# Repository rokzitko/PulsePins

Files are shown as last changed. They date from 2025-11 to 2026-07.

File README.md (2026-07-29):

# PulsePins Pulse Sequencer




PulsePins is an open-hardware FPGA pulse sequencer for laboratory timing and digital control. The released DE10-Nano design provides 32 digital outputs and a 10 ns programmable time step at a 100 MHz streamer clock. Use it for triggers, gates, digital buses, and DAC or DDS control; it does not generate analog or RF waveforms directly.

## Start here

Choose the path that matches what you want to do first:

| Goal | Start here |
| ---- | --- |
| Bring up a DE10-Nano | [Quick start](docs/docs/quick_start.md) |
| Choose a command or API | [Tool chooser](docs/docs/choose_tool.md) |
| Follow a complete lab workflow | [Worked examples](docs/docs/examples.md) |
| Understand the sequencer | [Sequencer model](docs/docs/sequencer_model.md) |
| Modify or extend PulsePins | [Hacking guide](HACKING.md) and [extension cookbook](docs/docs/extension_cookbook.md) |

## At a glance

| Item | Released DE10-Nano design |
| ---- | --- |
| Digital output | 32-bit bus, 3.3 V LVTTL |
| Timing | 10 ns programmable time step at a 100 MHz streamer clock |
| Sequence delivery | HPS-driven FIFO or memory-backed DMA transfers up to 512 MB |
| Control | Command-line tools, C++, Python, SCPI-style TCP, and a browser interface |
| Checks | FPGA readback encoder, CRC and FIFO diagnostics, and board self-tests |
| Design files | SystemVerilog/Verilog RTL, software, and KiCad sources under the MIT License |

## Documentation

[User and reference manual](http://auger.ijs.si/pulsepins/site/) ([source](docs/docs/index.md))

Useful contributor documents:

* [Hacking guide](HACKING.md)
* [Contribution guide](CONTRIBUTING.md)
* [Build and deployment](docs/docs/build.md)
* [Development guide](docs/docs/hacking.md)

## Recipes

Reusable command examples for the PulsePins command-line tools are stored in [`recipes/`](recipes/).
These files are separate from `tests/` so test executables and example command invocations are easier to find.

## License

This project is released under the MIT License. You may use, copy, modify, merge, publish, distribute, sublicense,
and/or sell the software and FPGA firmware (including RTL sources and generated bitstreams), including in commercial
and closed-source products. The only conditions are that you preserve the original copyright and license notice in all
substantial portions of the software/firmware, and that the software and firmware are provided “as is”, without any
warranty or liability on the part of the authors.

If you use PulsePins in scientific work, please cite:

> R. Žitko, *PulsePins: Open-hardware digital pulse sequencer for time-resolved experiments*, Zenodo (2025), [doi:10.5281/zenodo.17903233](https://doi.org/10.5281/zenodo.17903233).

### BibTeX

```bibtex
@misc{pulsepins_1_0,
  author       = {Žitko, Rok},
  title        = {PulsePins: Open-hardware digital pulse sequencer for time-resolved experiments},
  year         = {2025},
  publisher    = {Zenodo},
  version      = {1.0},
  doi          = {10.5281/zenodo.17903233},
  url          = {https://doi.org/10.5281/zenodo.17903233}
}
```

## Acknowledgments

This project incorporates code from the project [rsyocto](https://github.com/robseb/rsyocto) (c) Robin Sebastian, licensed under the MIT License.
See `third_party/rsyocto/LICENSE` for details.

[Rok Zitko](http://auger.ijs.si/nano), [rok.zitko@ijs.si](mailto:rok.zitko+pulsepins@ijs.si), 2025

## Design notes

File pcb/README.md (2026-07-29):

KiCad design files for printed-circuit boards ("ppshields"). These are reference designs for a quick start and
testing. The idea is that users modify these designs for their particular needs.

* ppshield_pmod: ppshield with Pmod interfaces

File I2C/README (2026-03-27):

i2cdetect -l

sudo i2cdetect -y 1

sudo i2cdetect -y -r 1

sudo i2cdetect -y -r -a 1

Note: the scripts require `smbus2`: `pip3 install smbus2`

Fix the version number in `gpg-1.13.1_unknown-py3.8.egg-info`:
`/usr/lib/python3.8/site-packages/gpg-1.13.1_unknown-py3.8.egg-info`

Remove `-unknown`.

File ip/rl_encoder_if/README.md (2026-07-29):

PulsePins readback / run-length encoder subsystem.

This directory contains the RTL used to observe `qout` activity, compress it back into run-length-encoded elements, and expose that captured stream to software for verification and debugging.

## Main files

- `rl_encoder_if.sv` - Avalon-ST/Avalon-MM wrapper around the readback encoder core
- `rl_encoder.sv` - core run-length encoder plus dual-clock FIFO buffering
- `rl_config.vh` - shared widths and configuration constants

## Architecture overview

The readback path is the mirror image of the streamer datapath:

1. sampled output symbols arrive on `qin`
2. normal builds sample valid input words on `qin_clk`; the alternate strobe-clocked mode is dormant behind `WEIRD_CLOCK`
3. `rl_encoder.sv` groups consecutive equal values into `{count, value}` runs
4. a dual-clock FIFO decouples the sampled input domain from HPS-side reads
5. `rl_encoder_if.sv` exports the captured runs as Avalon-ST data and adds status/control registers

This subsystem is mainly used for:

- self-test of streamer output correctness
- CRC-based integrity checking
- debugging external signals when the physical output enable `oe` is deasserted

## Programming model

`rl_encoder_if.sv` exposes:

- Avalon-ST output carrying encoded `{control=0, counter, data}` elements
- Avalon-MM control/status registers for reset, active-mode status, pulse count, FIFO-empty state, overflow, and CRC32

The wrapper also maintains a pulse counter and CRC in the sampled-input domain so software can compare the observed stream against the transmitted reference.

## Reading order for maintainers

1. `rl_encoder_if.sv`
2. `rl_encoder.sv`
3. `rl_config.vh`
4. `c++/readback.hh`
5. `docs/docs/readback.md`

## Verification and related docs

- subsystem overview: `docs/docs/readback.md`
- related streamer docs: `docs/docs/streamer.md`
- HPS-side wrapper: `c++/readback.hh`

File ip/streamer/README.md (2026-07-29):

PulsePins streamer subsystem.

This directory contains the RTL for the main pulse-sequence engine: it accepts encoded sequence elements on the control side, expands them into output updates, applies configured trigger and gating behavior, and emits the final `qout` stream in the selected streaming clock domain.

## Main files

- `st_interface.sv` - Avalon-ST data ingress plus Avalon-MM control/status wrapper around the streamer core
- `streamer.sv` - top-level datapath glue joining FIFOs, decoder, trigger chain, and output flow control
- `config.vh` - shared widths, control-bit definitions, register enums, and FIFO sizing parameters
- `input_fifo.sv` - control-side FIFO that buffers incoming sequence elements
- `preprocessor.sv` - optional second-level replay/store stage for short subsequences
- `rl_decoder.sv` - run-length decoder that expands encoded elements into output updates
- `output_fifo.sv` - dual-clock FIFO bridging control-side decode logic into the `streamer_clk` output domain
- `and_trigger.sv` - simple single-stage mask/pattern trigger block
- `chain_trigger.sv` - multi-stage trigger program loader and runtime trigger state machine
- `prng.sv` - pseudorandom data source used by PRNG elements

## Architecture overview

The streaming path is intentionally split into two domains:

1. control-side logic in `clk`
2. output-side logic in `streamer_clk`

At a high level the flow is:

1. HPS-side software or the DMA engine sends encoded `{control, counter, data}` elements into `st_interface.sv`
2. `st_interface.sv` byte-swaps them into the internal layout and forwards them to `streamer.sv`
3. `input_fifo.sv` absorbs bursty HPS-side traffic and provides backpressure through `asi_ready`
4. regular elements go to `rl_decoder.sv`, while trigger elements are consumed by `chain_trigger.sv`
5. decoder output is buffered by `output_fifo.sv`, which crosses into `streamer_clk`
6. `chain_trigger.sv` decides when output is allowed to advance
7. gating and stop logic further qualify output reads from the output FIFO
8. `qout`, `qout_valid`, and `qout_strobe` become the external streamer outputs

## Programming model

The external software-visible wrapper is `st_interface.sv`.

It exposes:

- an Avalon-ST ingress port carrying encoded sequence elements
- an Avalon-MM control/status port for trigger control, output override, gating, CRC readout, and FIFO statistics
- direct trigger and gate inputs used at runtime in the `streamer_clk` domain

The Avalon-ST ingress accepts a channel tag for integration with channel-aware width adapters. `st_interface.sv` ignores the tag after the adapter has used it to keep upstream partial elements separate.

Important behavioral points:

- regular sequence elements describe output updates and durations
- trigger elements are intercepted before decode and loaded into the trigger chain
- `initial_value` defines the observable output before the trigger fires
- `qout_select` can override the normal streamer output for debugging or manual output driving
- `gate_enable` controls whether the output-side FIFO is allowed to advance once triggering has started
- `done` reflects successful completion of the buffered output stream
- `buffer_error` indicates output-side underrun
- static output/gating configuration written from Avalon-MM crosses into `streamer_clk` as a
  coherent CDC bundle and is applied only while the streamer is idle or in streamer reset
- live status, CRC, output value, and output-side counter readout values are control-domain snapshots
  of `streamer_clk` state, not direct asynchronous samples

## Key customization points

If you want to customize the streamer, the usual starting points are:

- register map or external control behavior - `st_interface.sv`
- encoded element semantics - `config.vh`, `rl_decoder.sv`, `preprocessor.sv`
- trigger behavior - `chain_trigger.sv`, `and_trigger.sv`
- output pacing, strobe timing, underrun behavior - `output_fifo.sv`
- buffering and throughput tradeoffs - `config.vh`, `input_fifo.sv`, `output_fifo.sv`

## Reading order for maintainers

1. `config.vh`
2. `st_interface.sv`
3. `streamer.sv`
4. `rl_decoder.sv`
5. `preprocessor.sv`
6. `output_fifo.sv`
7. `chain_trigger.sv`

That order follows the boundary from software-visible control interfaces toward the deeper implementation details.

## Verification and related docs

- run RTL tests: `make -C ip test`
- subsystem overview: `docs/docs/streamer.md`
- low-level hardware details: `docs/docs/details.md`
- CDC and clock ownership: `docs/docs/clock_domain.md`
- readback verification path: `docs/docs/readback.md`

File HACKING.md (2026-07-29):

# Hacking on PulsePins

PulsePins is meant to be hacked on, adapted, and extended.

Contributions are welcome across RTL, C++, Python, documentation, tests, board support, examples, measurement workflows, and experimental integration ideas. You do not need to start with a large feature; small fixes, examples, and documentation improvements matter too.

## Good first contribution areas

- Documentation: clean up wording, expand guides, add examples, improve onboarding
- C++ tools: improve `pptool`, add options, improve formatting, add tests for parsing and sequence handling
- Python bindings: improve packaging, examples, and tests in `python/`
- RTL and simulation: add or improve testbenches under `ip/`
- Recipes and examples: add practical command sequences in `recipes/`
- Worked examples: capture real lab workflows, timing setups, and instrument integrations

## Contribution paths

### No hardware required

You can contribute without a board if you work on:

- documentation under `docs/` and top-level `README*` files
- sequence parsing and representation in `c++/`
- Python bindings in `python/` (build/import testing on a development machine is useful, but production Python builds still happen on the DE10-Nano)
- RTL testbenches and simulation-only RTL work under `ip/`
- recipes, examples, and test infrastructure

Good first commands:

```bash
make dev-check
make -C ip test
```

`dev-check` is the default local contributor check.
`make -C ip test` runs RTL simulation testbenches if the required simulator tools are installed.

For Python specifically:

- running `make -C python USE_PREGENERATED=1 build test-host` on a development machine checks the host-buildable bindings and non-hardware tests
- the supported production build of the Python modules still happens on the DE10-Nano
- true Python cross-compilation is not currently supported

### Hardware helps, but is not always required

These areas benefit from access to a board but can still be developed partially without one:

- CLI tool UX and error messages
- sequence-generation logic
- counter/timestamp/frequency-meter docs and helper code
- deployment scripts and image staging

### Hardware required

You will usually need a DE10-Nano and the PulsePins bitstream/runtime environment for:

- end-to-end streamer behavior
- timing-sensitive measurements
- clocking, PPS, and external trigger validation
- board bring-up and interface-shield testing
- hardware-backed regression verification

The default documented hardware baseline is intentionally minimal:

- `DE10-Nano` only
- latest released pre-built PulsePins image
- no extra wiring for the baseline verification flow

For that baseline, the board:

- obtains its network address via DHCP
- can be reached over SSH as user `root` with password `eit`
- can also be accessed over the UART USB serial interface if needed

## Build/test map

| Area | Main location | Hardware needed | Main command |
| ---- | --- | --- | --- |
| Local checks | repo root | no | `make dev-check` |
| Docs | `docs/` | no | `make -C docs site` |
| C++ tools | `c++/` | not always | `make -C c++ build` |
| Python bindings | `python/` | not always | `make -C python USE_PREGENERATED=1 build test-host` |
| RTL simulation | `ip/` | no | `make -C ip test` |
| Fast board smoke | repo root | yes | `make board-smoke` |
| Full FPGA build | repo root | toolchain required | `make` |
| Board deployment | repo root, `image/` | yes | `make copy_all` |

## Baseline hardware workflow

The baseline bring-up and verification flow is:

1. boot the latest released pre-built image on a DE10-Nano
2. connect over SSH
3. run `run_all_tests`

Expected result:

- the command exits successfully
- it prints a clear pass message
- it currently takes a few minutes, roughly around 7 minutes at the default 100 MHz streaming frequency

That runtime should be treated as approximate; it may change as the test suite grows.

## Updating a board from the current repository state

The current recommended contributor update flow is:

1. build the latest GitHub version
2. run `make copy_all`
3. SSH to the DE10-Nano
4. from the root home directory on the board, run:

```bash
FPGA-writeConfig -f pulsepins.rbf
```

5. run `run_all_tests` again

For now, treat this FPGA reload step as required after `make copy_all`.

## Optional hardware profile: PP_PMOD

`PP_PMOD` is an optional reference shield. It is not part of the required baseline, and it is not a prebuilt product.

Its KiCad design is published so people can build it, modify it, or use it as a starting point for custom boards.

Useful capabilities include:

- Pmod connectors for expansion modules
- one SMA trigger input with comparator threshold control
- two buffered SMA outputs
- external clock and PPS inputs
- Qwiic I2C connector
- optional on-board `AD5693` DAC
- optional on-board `MCP9808` temperature sensor
- status LEDs

Verified/useful optional workflows around `PP_PMOD` include:

- LED Pmod modules for visible output patterns
- onboard `MCP9808` temperature reads
- external `TMP117` over Qwiic/I2C
- `Pmod DA3` for fixed-voltage DAC output
- external clock verification with `ppfreq`
- PPS verification with `ppts`
- buffered-output use with oscilloscopes, logic analyzers, spectrum analyzers, and counters

Known-good external clock examples include:

- lab signal generators
- OCXO/GPSDO references
- CMOS oscillator modules

PPS has been checked with a GNSS receiver PPS output.

## Suggested first contributions

- improve a doc page that feels too author-centric
- add a missing example or recipe
- improve a command-line help message
- add a small simulation test case for an IP block
- fix naming consistency or formatting in tool output
- document a real hardware workflow once you have verified it

Worked examples are especially valuable. Example-driven documentation is one of the best ways to make PulsePins approachable.

### Community-contribution areas that would help a lot

- worked examples from real physics/lab scenarios
- Pmod module and sensor writeups
- custom shield or daughterboard notes
- wiring diagrams and timing diagrams
- screenshots, scope traces, and logic-analyzer captures
- photos of custom hardware setups

Typical application areas where community examples would be especially appreciated include:

- pulse sequencing for lasers, shutters, and detectors
- synchronized triggering of cameras and instruments
- delay generation for time-resolved measurements
- DDS/DAC control for frequency or amplitude sweeps

Lua scripting is also a promising extension area, but it is still early-stage and only lightly documented.

## Reliability matters

High reliability is a major project goal.

Simulation-only RTL work is therefore very valuable and strongly encouraged, especially when it improves:

- testbenches
- interface validation
- CDC and reset correctness
- executable documentation of behavior

Testbenches are useful not only for verification, but also for documenting interfaces and intended functionality.

## Community interaction

For now, use GitHub Issues for:

- bug reports
- ideas and feature requests
- questions
- example writeups
- hardware setup notes

## Working style

- Prefer small, focused changes
- Keep documentation close to the code it explains
- If behavior changes, update docs and tests in the same change when practical
- If hardware behavior is uncertain, document the uncertainty instead of guessing

## Where to look next

- `CONTRIBUTING.md`
- `docs/docs/build.md`
- `docs/docs/development.md`
- `docs/docs/testing.md`
- `docs/docs/getting_started_no_hardware.md`
- `docs/docs/getting_started_hardware.md`

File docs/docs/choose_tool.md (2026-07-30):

# Choose the right tool

PulsePins exposes the same hardware through task-specific commands, C++ and Python APIs, a SCPI-style network service, and a browser interface. Start with the narrowest interface that already matches the job.

This page describes the current source-tree command set. Older released images may provide fewer commands; check the selected release notes when a tool is unavailable.

## Choose by task

| Goal | Start with | Why |
| ---- | --- | --- |
| Set up and validate a released board | [Quick start](quick_start.md) | linear image, access, self-test, and first-output procedure |
| Generate a periodic signal, PWM, or finite burst | [`ppfg`](ppfg.md) | direct frequency, period, duty-cycle, and burst controls |
| Emit a pulse after a trigger and delay | [`ppdelay`](ppdelay.md) | one-shot delay-generator workflow |
| Run the smallest live output smoke test | [`pphelloworld`](pphelloworld.md) | immediate repeating output without a sequence file |
| Play a saved sequence | [`ppplay`](ppplay.md) | canonical text plus derived binary and VCD input |
| Capture, inspect, or replay qualified output samples | [`ppread`](ppread.md) and [Readback](readback.md) | `qout_valid`-qualified runs as text, VCD, or a current-build binary snapshot |
| Run built-in hardware checks | [`pptest`](pptest.md) and [Testing procedures](testing.md) | streamer, trigger, preprocessor, and readback validation |
| Measure clocks | [`ppfreq`](ppfreq.md) | external, internal, streamer, and core clock measurements |
| Inspect PPS or timestamp events | [`ppts`](ppts.md) | timestamp stream and interval reporting |
| Exercise event counters | [`ppcounter`](ppcounter.md) | built-in deterministic or pseudorandom counter test sequences |
| Monitor AUX pin levels | [`ppaux`](ppaux.md) | formatted sampling of the read-only CLI path |
| Read the PP_PMOD temperature sensor | [`pptemp`](pptemp.md) | MCP9808 board-peripheral access |
| Debug trigger sources and masks | [`pptrig`](pptrig.md) | trigger-combiner configuration and live state |
| Inspect or override output routing | [`ppqout`](ppqout.md) | output-combiner modes, masks, and force values |
| Reset an interrupted or infinite stream | [`ppreset`](ppreset.md) | return the primary streamer to a known idle state |
| Calculate a PLL profile without hardware | [`pllcalc`](pllcalc.md) | standalone clock-profile calculation |
| Automate from a script or notebook | [Python API](python.md) | generated sequences and experiment integration |
| Add a command or direct hardware wrapper | [C++ API](cpp.md) | native access to the existing runtime and hardware classes |
| Control a board over the network | [`ppscpi`](ppscpi.md) | line-oriented remote instrument control |
| Operate interactively from a browser | [`ppwebgui`](ppwebgui.md) | live state plus trigger, routing, and sequence controls |

## Choose an interface layer

| Interface | Best fit | Main tradeoff |
| --- | --- | --- |
| Command-line tools | immediate shell use and existing single-purpose operations | limited composition beyond shell scripts |
| Python API | notebooks, sweeps, generated sequences, and larger measurement scripts | board-native bindings and workstation SCPI clients have different deployment models |
| C++ API | new tools, direct wrappers, and performance-sensitive board-side work | requires native build and lower-level project knowledge |
| SCPI server | remote orchestration and instrument-style clients | unauthenticated control; restrict the bind address or use a trusted network |
| Web interface | interactive setup, status, and manual operation | intended for trusted networks rather than unattended automation |

Use the command line first when a dedicated tool already provides the operation. Move to Python or C++ when sequence generation, repetition, error handling, or integration logic starts dominating the shell commands.

## Sequence file formats

| Format | Use it when |
| --- | --- |
| PulsePins text | the sequence should remain readable and editable |
| VCD | a flattened waveform should be inspected in a waveform-oriented tool and the documented projection limits are acceptable |
| PulsePins binary (`.ppbin`) | a normalized current-build sequence snapshot is useful and matching field widths are available |

PulsePins text is the canonical user-facing format. See [PulsePins text sequence format](sequence_format.md), [`ppplay`](ppplay.md), and [`ppread`](ppread.md) for fidelity and interface-specific behavior.

## Common paths

First board:

1. Follow [Quick start](quick_start.md).
2. Confirm `run_all_tests` reports `SUCCESS`.
3. Follow [First finite output](manual/first_output.md).
4. Select the next command or interface from the task table above.

Repeatable capture and replay:

1. Start [`ppread`](ppread.md) before the signal source and keep the capture running.
2. Generate with [`ppfg`](ppfg.md), [`ppdelay`](ppdelay.md), or a custom sequence while capture is active.
3. Inspect VCD or text output.
4. Replay with [`ppplay`](ppplay.md).

Readback records live qualified samples; it cannot recover a finite waveform that completed before `ppread` started, no-strobe states, or the elapsed time in invalid gaps. See [Capture and replay](manual/capture_replay.md) for the two-terminal workflow.

Peripheral transaction:

1. Validate the base output path with [`pptest`](pptest.md).
2. Check routing with [`ppqout`](ppqout.md) if needed.
3. Generate the transaction with the C++, Python, or helper-tool layer.
4. Play and verify the resulting sequence.

## Experimental reference

[`ppgpsdo`](ppgpsdo.md) remains an experimental GPSDO reference implementation rather than a recommended user-manual workflow. Establish and verify the complete oscillator-to-timestamp feedback path before treating it as a control loop for laboratory use.

For complete command-and-observation chapters, continue with the [User manual](examples.md).

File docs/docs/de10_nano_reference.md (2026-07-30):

# DE10-Nano signal reference

This page describes the board-facing signals in the released 32-bit DE10-Nano design. The assignments in [`pulsepins.sv`]({{ source_file("pulsepins.sv") }}) and [`pulsepins.qsf`]({{ source_file("pulsepins.qsf") }}) are authoritative; use the Terasic DE10-Nano documentation for physical header pin numbers and board-level electrical limits.

## Electrical baseline and output enable

The released design uses 3.3 V LVTTL signaling on its PulsePins-facing GPIO and Arduino-header signals.

The 32 main `qout` pins use bidirectional FPGA buffers. They default to high impedance while physical output enable `oe` is low, allowing the readback and counter paths to sample externally driven levels. The same `oe` also controls the bidirectional `streamer_qout_valid` and `streamer_qout_strobe` pads. When `oe` is high, PulsePins drives these signals. Avoid connecting an enabled output to another active driver.

Use high-impedance instrument inputs on unbuffered FPGA pins. Do not apply a direct 50 ohm scope termination unless an external driver or buffer has been designed for that load.

## GPIO signal map

The main output and control signals use the two 40-pin DE10-Nano GPIO headers. The image below gives the physical overview.

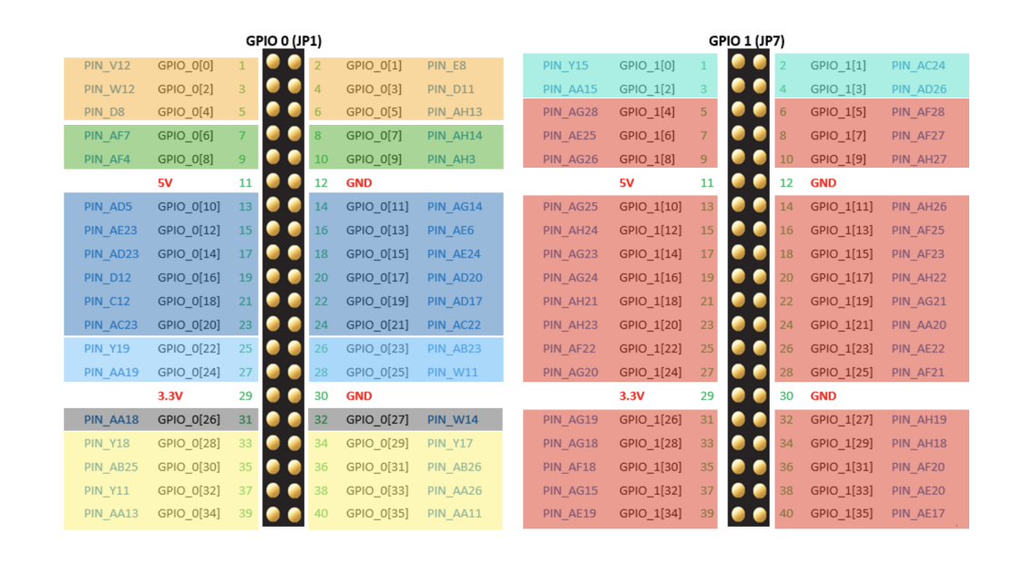
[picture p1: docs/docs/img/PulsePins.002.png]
PulsePins pinout


Color code used in the diagram:

| Color | Meaning |
| ----- | --- |
| <font color="orange">orange</font> | clocking |
| <font color="green">green</font> | status |
| <font color="darkblue">blue</font> | triggering |
| <font color="#FFD580">yellow</font> | AUX I/O |
| <font color="cyan">cyan</font> | external clock inputs |
| <font color="red">red</font> | output data |

The indexes below are positions in the top-level GPIO arrays, not physical connector pin numbers. GPIO0 bits 22-25 use the current `EXTRA_SETB` debug selection; an alternate build can expose streamer trigger visibility instead.

Quick connections for the first-output manual chapters:

| Signal | Logical index | DE10-Nano header pin | FPGA pin |
| --- | --- | --- | --- |
| `qout[0]` | GPIO1[4] | GPIO 1 (`JP7`) pin 5 | `PIN_AG28` |
| `qout[1]` | GPIO1[5] | GPIO 1 (`JP7`) pin 6 | `PIN_AF28` |
| ground | - | GPIO 1 (`JP7`) pin 12 or pin 30 | - |

Use the numbered connector drawing above to verify orientation before attaching a probe.

| Connector | Index | Debug label | Signal | Function |
| --- | ----- | --- | --- | --- |
| GPIO0 | 0 | D0 | `streamer_qout_strobe` | output strobe pulse |
|  | 1 | D1 | `oe` | physical output enable |
|  | 2 | D2 | `streamer_clk` | selected output clock |
|  | 3 | D3 | `streamer_qout_valid` | output sample qualifier |
|  | 4 |  | `activity` | recent output activity |
|  | 5 |  | `heartbeat` | FPGA image and reference-clock indicator |
|  | 6 | D8 | `trigger_armed` | waiting for a trigger event |
|  | 7 | D9 | `trigger_activated` | triggered and advancing output |
|  | 8 | D10 | `done` | clean stream completion |
|  | 9 | D11 | `buffer_error` | output FIFO underrun detected |
|  | 10 |  | `ext_trigger_enable` | external trigger enable input |
|  | 11 |  | `ext_trigger_force` | external trigger force input |
|  | 12 |  | `ext_trigger_reset` | external trigger reset input |
|  | 13 |  | `gate_in` | output-advancement gate input |
|  | 21:14 |  | `ext_trigger_in[7:0]` | external trigger inputs |
|  | 22 | D12 | `rnd1` | synthetic random debug output (`EXTRA_SETB`) |
|  | 23 | D13 | `rnd2` | synthetic random debug output (`EXTRA_SETB`) |
|  | 24 | D14 | `0` | constant-low debug output (`EXTRA_SETB`) |
|  | 25 | D15 | `0` | constant-low debug output (`EXTRA_SETB`) |
|  | 26 |  | I2C SDA | HPS I2C data |
|  | 27 |  | I2C SCL | HPS I2C clock |
|  | 35:28 |  | `AUX[7:0]` | auxiliary I/O |
| GPIO1 | 0 |  | `EXT_CLKp` | external streamer-clock input |
|  | 1 |  | `PPS_IN` | pulse-per-second input |
|  | 2 |  | `PPCLK1` | reserved; unconnected in the released top-level design |
|  | 3 |  | `PPCLK2` | reserved; unconnected in the released top-level design |
|  | 35:4 | D[7:4] for `qout[3:0]` | `streamer_qout[31:0]` | main output bus |

## Arduino header

The released build also presents selected output and clock signals on the Arduino header for probing and tests:

| Arduino signal | PulsePins signal |
| --- | --- |
| D0-D7 | `streamer_qout[7:0]` |
| D8 | `streamer_clk` |
| D9 | `core_clk` |
| D10 | `int_clk` |
| D11 | `streamer_qout[0]` |
| D12 | `streamer_qout[1]` |
| D13 | `PPS_XTAL` |
| D14-D15 | constant low |

These Arduino-header signals are direct output assignments and are not released by `oe`. Do not drive them from external logic; use high-impedance probes or connect them only to compatible inputs.

## On-board LEDs

LED0 is closest to the Ethernet connector. The LEDs are active high and show:

| LED | Signal | Meaning |
| --- | --- | --- |
| 0 | `trigger_armed` | waiting for a trigger |
| 1 | `trigger_activated` | trigger fired |
| 2 | `done` | clean stream completion |
| 3 | `buffer_error` | output FIFO underrun |
| 4 | `streamer_trigger_in[0]` | combined trigger input 0 |
| 5 | `streamer_trigger_in[1]` | combined trigger input 1 |
| 6 | `activity` | at least one valid output event was observed in the recent 200 ms window |
| 7 | `heartbeat` | FPGA image loaded and reference clock running |

## Manual trigger controls

The miscellaneous trigger-combiner input receives these on-board controls:

* KEY0 and KEY1 provide trigger inputs 0 and 1
* switch 0 provides trigger enable
* switch 1 provides trigger force
* switch 2 provides trigger reset
* `PPS_IN` provides miscellaneous trigger input 2

The switches are off when positioned toward the Arduino connector. See the [Combiner subsystem](combiner.md) for source selection and [`pptrig`](pptrig.md) for live diagnostics.

## Trigger monitor PIO

`pio_trig_monitor` exposes both the external trigger pins and the post-combiner signals to software.

External signals occupy the low fields:

| Bits | Signal |
| ---- | --- |
| 7:0 | `ext_trig_in` |
| 8 | `ext_trig_enable` |
| 9 | `ext_trig_force` |
| 10 | `ext_trig_reset` |

Signals seen by the streamer occupy the upper fields:

| Bits | Signal |
| ---- | --- |
| 23:16 | `streamer_trig_in` |
| 24 | `streamer_trig_enable` |
| 25 | `streamer_trig_force` |
| 26 | `streamer_trig_reset` |

## Auxiliary I/O

The released design exposes eight bidirectional `AUX` pins. Direction is selected independently for each bit through `pio_cfg`: `0` selects input, `1` selects output, and all bits default to input after reset. `pio_aux` holds output values and reports sampled pin levels.

[`ppaux`](ppaux.md) samples the bus but does not configure direction or drive output values. The [PP_PMOD hardware reference](pp_pmod_reference.md) documents the `J12` AUX connector.

## Related hardware pages

* [Hardware setup](getting_started_hardware.md)
* [ppboards shield overview](ppboards.md)
* [PP_PMOD overview](pp_pmod.md)
* [PP_PMOD hardware reference](pp_pmod_reference.md)
* [Readback](readback.md)

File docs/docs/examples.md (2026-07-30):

# User manual

This manual is organized around finite, reproducible laboratory tasks. It describes current `main`, host/FPGA ABI 6, and the released 32-bit DE10-Nano design. Older binary images may not provide every command or option used here; use documentation and software from the same revision.

The chapters are source-reviewed procedures, not claims of bench validation. Record the actual hardware, clock, software revision, commands, and observations whenever you run one.

## Validation status

| Status | Meaning |
| --- | --- |
| source-reviewed | commands and stated behavior were checked against current source and reference documentation |
| board-tested | the complete procedure was run on a matching DE10-Nano build |
| bench-validated | wiring and expected physical behavior were checked with the stated instruments |
| experimental | the workflow is incomplete, setup-dependent, or lacks enough evidence for a supported lab procedure |

Only `source-reviewed` status is asserted by these pages unless a chapter includes a dated validation record.

## Core chapters

| Chapter | Outcome | Additional hardware | Status |
| --- | --- | --- | --- |
| [First finite output](manual/first_output.md) | generate ten periods on only `qout[0]` and return the bus to zero | high-impedance scope or logic analyzer | source-reviewed |
| [First text sequence](manual/text_sequence.md) | author and play the canonical PulsePins text format | optional high-impedance probe | source-reviewed |
| [Triggered one-shot delay](manual/triggered_delay.md) | use KEY0 to release one delayed pulse on `qout[0]` | high-impedance scope or logic analyzer | source-reviewed |
| [Capture and replay](manual/capture_replay.md) | record a live finite waveform and replay the canonical text capture | two board terminals; optional waveform viewer | source-reviewed |
| [Workstation Python timeline](manual/python_timeline.md) | generate, inspect, and stream a finite Timeline through restricted SCPI | workstation and trusted network | source-reviewed |

Read the [PulsePins text sequence format](sequence_format.md) before hand-authoring control-flow, trigger, replay, or relative-update records.

## Before a chapter

1. Complete [Quick start](quick_start.md) or deploy a matching current-source build.
2. Confirm that the host software and FPGA image report the expected ABI.
3. Disconnect incompatible external drivers and loads.
4. Use 3.3 V-compatible, high-impedance inputs and a common ground.
5. Record the active streamer clock instead of assuming 100 MHz.
6. Keep the chapter's explicit output masks and final value.

The manual uses finite operations by default. Command-reference pages may also describe continuous or low-level modes; those modes require their own interrupt, reset, output-state, and safe-rewiring procedure.

## Reference-only workflows

The following capabilities remain documented, but they are not yet presented as supported manual chapters:

| Area | Current reference | Why it is not a core chapter |
| ---- | --- | --- |
| external clock measurement | [`ppfreq`](ppfreq.md) and [Frequency meter](freq_meter.md) | source voltage, nominal frequency, termination, selected channel, and negative control must be specified for a reproducible setup |
| external PPS timestamping | [`ppts`](ppts.md) and [Timestamp capture](timestamp.md) | a chapter must use explicit `-pps_in`, finite sample counts, and a disconnected-input negative control |
| PP_PMOD temperature | [`pptemp`](pptemp.md) and [PP_PMOD hardware reference](pp_pmod_reference.md) | shield revision, populated sensor, bus visibility, finite sample count, and expected address should be recorded |
| SPI/DDS generation | [C++ SPI sequence generation](cpp.md#spi-sequence-generation) | generator path, output-bit wiring, decoder clock, peripheral reference clock, and measured result require setup-specific validation |
| GPSDO controller | [`ppgpsdo`](ppgpsdo.md) | experimental reference implementation; the complete oscillator feedback path must be independently established and verified |

These entries should become chapters only after their setup, finite commands, expected result, cleanup, and positive and negative controls have been recorded.

## Choose another interface

Use [Choose the right tool](choose_tool.md) when the task does not match a chapter. Command pages provide option-level reference, while [C++](cpp.md), [Python](python.md), [SCPI](ppscpi.md), and the [web interface](ppwebgui.md) describe programmatic control layers.

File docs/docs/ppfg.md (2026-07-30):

# ppfg - PulsePins Function Generator

ppfg is a simple "function generator" for binary signals.

Command line switches:

* ``-period``: time period (floating point value); the unit can be specified attached to the
number with no space (accepted suffixes are: ns; us; ms; s=sec=secs; min; h=hr=hrs; d=day=days, u
stands for micro, case insensitive; for example 20ms), default unit is seconds; no default value
* ``-freq``: frequency (floating point value); the unit can be specified attached to the number with
no space (accepted suffixes are: uHz, mHz, Hz, kHz, MHz, GHz, u stands for micro, case insensitive
except for m/M; for example 5MHz), default unit is Hz; no default value
* ``-duty``: duty cycle as a percentage of the 'on' signal; fractional values are allowed (floating point);
default value is 50
* ``-servo``: angle setting for testing [servo motors](#servo-motors) using pulse-width modulation (PWM);
the angle argument is required when the switch is used
* ``-v0``: output pattern for low state (default: ``0x00000000``)
* ``-v1``: output pattern for high state (default: ``0xFFFFFFFF``)
* ``-start0``: set the first pattern presented on the output to the low state (instead of high state; default: off)
* ``-delay``: delay after trigger before generating the output sequence (in seconds, same syntax as for
period; default: ``0``)
* ``-p``: trigger pattern (default: ``0b00000001``)
* ``-m``: trigger mask (default: ``0b00000001``)
* ``-i``: initial output value before triggering (default: ``0``)
* ``-trig``, ``-autotrig``: do not wait for external trigger, automatically start (default: off)
* ``-gate``: gate settings, specified by a [gate string](#gate-settings) (default: disabled)
* ``-gate_debug``: start the program in gate debug mode; gate signal state is dumped
every 100 ms (default: off)
* ``-core_pll``, ``-core_pll_charge_pump``, ``-core_pll_bandwidth``: core-clock PLL settings, as explained [here](pptest.md#pll-settings)
* ``-int_pll``, ``-int_pll_charge_pump``, ``-int_pll_bandwidth``: internal streamer-clock PLL settings, as explained [here](pptest.md#pll-settings)

Specify one positive waveform timing source with ``-period`` or ``-freq``; these two options are mutually exclusive.
In servo mode, ``-servo`` supplies the pulse width from the requested angle. If neither ``-period`` nor
``-freq`` is supplied, servo mode uses the standard 20 ms / 50 Hz servo PWM period. If ``-period`` or
``-freq`` is supplied together with ``-servo``, that explicit timing is used and the duty cycle is
recomputed from the servo pulse width. The explicit period must not be shorter than that width; use a
longer period when a nonzero low phase is required.

There are two modes of operation, burst mode and continuous mode.

The default high value is `0xFFFFFFFF`, which drives all 32 output bits high. User-facing procedures should set `-v1`, `-v0`, and the final value explicitly. Start with the finite [`qout[0]` manual chapter](manual/first_output.md) rather than relying on these defaults.

## Gate settings

The gate controls whether streamer output is allowed to advance and is configured with a 'gate string': `-gate en:gate_in_en:mask`.

* en: enable is a boolean (t=T=1, f=F=0)
* gate_in_en: enable dedicated gate input (gate_in)
* mask: trigger mask (default: ``0b00000000``); signals on the trigger port can also be used to
open the gate and allow output advancement

## Burst mode

Activated with ``-burst N``. The parameters are:

* ``-burst``: number of pulse repetitions after activation; the argument is required when burst mode is used
* ``-t``: final value (default: ``0``)
* ``-n_max``: maximum number of bursts (default: ``1``; ``0`` means infinity)

`-burst 0` also encodes infinite replay in the FPGA, so use strictly positive `-burst` and `-n_max` values for a finite run. With `-trig` or `-autotrig`, a positive finite burst is forced after queueing; without either option, it is only armed for the selected trigger condition. In both cases the command returns without waiting for hardware completion. An untriggered burst can therefore remain latent indefinitely, and shell-prompt return does not mean the final value has been reached.

## Continuous mode

Activated with ``-cont`` (default: off).

Continuous mode keeps the foreground process paused after it queues and either forces or arms the sequence. Interrupting that process does not itself clear repeating or armed hardware state.

## Stopping infinite or armed output

`-burst 0` returns to the shell even though its replay becomes infinite after activation and never reaches the queued final value. `-n_max 0` keeps the host in an infinite enqueue loop until interruption or transport failure. Activated continuous mode is also unbounded, while any mode without `-trig` or `-autotrig` can remain armed. Interrupting either foreground loop does not clear hardware state. Run `ppreset -i 0x0` to cancel these states; this returns the bus to zero but leaves the physical output drivers enabled. Before connecting another driver, power down or release the bidirectional pins with `ppread -oe 0 -hard-timeout 100ms`.

## Servo motors

As a convenience, using the ``-servo`` switch, ppfg can generate an appropriate pulse-width modulation
signal for testing servo motors.

By default, ``-servo`` uses a 20 ms / 50 Hz PWM period and maps angles from 0 to 180 degrees onto 1 ms
to 2 ms high pulses. For example, ``-servo 90`` produces a 1.5 ms high pulse, i.e. 7.5% duty cycle at
the default 20 ms period.

If ``-period`` or ``-freq`` is also supplied, ppfg derives duty from the servo pulse width and the
explicit period. For example, ``-servo 90 -freq 100Hz`` uses a 10 ms period with a requested 1.5 ms
high pulse, i.e. 15% duty cycle before clock-count quantization. A period shorter than the requested
servo pulse yields a duty above 100% and is rejected.

In servo mode the duty cycle is derived from the angle, so ``-duty`` is ignored.

The servo option only generates the digital waveform. It does not define a safe servo power supply, ground connection, level interface, or current path; document those separately for the connected hardware.

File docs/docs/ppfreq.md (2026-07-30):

# ppfreq

`ppfreq` reads the on-board frequency-meter block and prints measured frequencies periodically.

For the underlying measurement block and API, see `freq_meter.md`.

The tool creates the shared `pp_freq_meter` wrapper, optionally reprograms the measurement-gate settings, waits one full measurement interval, and then prints formatted readings in a loop.

It uses the interface in [`c++/freq_meter.hh`]({{ source_file("c++/freq_meter.hh") }}), and the command implementation lives in [`c++/pptool_measurement.cc`]({{ source_file("c++/pptool_measurement.cc") }}).

Common options:

* `-gate_time T`: set the measurement gate time, for example `1s`
* `-gate_len N`: set the measurement gate length directly in clock cycles
* `-nr N`: number of measurements to print; `0` means run continuously
* `-freq_rescale X`: apply correction factor `X` to the reported frequencies; can also be set with `PP_FREQ_RESCALE`
* `-format F`: output format string, default `%t %e`

Measurement-gate configuration follows this order:

* if `-gate_time` is present, it is used
* otherwise `-gate_len` is used, defaulting to `500000`

The command uses an output format string. By default it uses `%t %e`, so it prints a wall-clock timestamp plus the external-clock reading.

### Displayed channels

The default output format prints:

* wall-clock timestamp
* external clock frequency

Format tokens:

| Token | Meaning |
| --- | --- |
| `%t` | wall-clock timestamp |
| `%c` | sample counter |
| `%e` | external clock frequency |
| `%i` | internal clock frequency |
| `%s` | selected streamer clock frequency |

Output behavior:

* each printed line is rendered from the selected output format
* frequency values use the same formatting as the shared frequency-meter wrapper

Longer gate intervals improve count-based frequency resolution but reduce the update rate.

Use `%%` in the format string for a literal percent sign.

### Typical examples

Measure using a 1-second measurement gate:

```bash
ppfreq -gate_time 1s -nr 5
```

Measure using a raw gate length of 1,000,000 reference-clock (`cnt_clk`) cycles:

```bash
ppfreq -gate_len 1000000 -nr 5
```

Print 20 measurements and stop:

```bash
ppfreq -nr 20
```

Apply a correction factor:

```bash
ppfreq -gate_time 1s -freq_rescale 0.99995 -nr 5
```

Show the external, internal-candidate, and selected streamer clock channels:

```bash
ppfreq -gate_time 1s -format "%t ext=%e int=%i streamer=%s" -nr 5
```

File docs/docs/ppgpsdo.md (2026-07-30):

# ppgpsdo

`ppgpsdo` is a reference implementation of a GPS-disciplined oscillator (GPSDO) using PPS from a GNSS receiver.

**Experimental status:** this command is not currently a supported user-manual workflow. It updates a DAC from paired PPS and `sigA` timestamps, but the operator must independently establish and verify that the selected `sigA` path observes the oscillator controlled by that DAC. Do not treat the documented command structure alone as evidence of a closed physical feedback loop.

It reuses the same timestamp-capture infrastructure as `ppts`, but instead of only printing events it pairs PPS and auxiliary timestamps, derives a timing error, and drives a DAC through a PID controller.

Requirements for investigating this implementation:

* target board running a matching current PulsePins host build and FPGA image
* pulse-per-second signal from a GNSS receiver applied to the PPS pin, with `-pps_in` supplied explicitly; otherwise the retained or reset-default crystal PPS source can be used
* an oscillator-derived event, normally divided to the same nominal one-event-per-second cadence as PPS, routed with electrically appropriate conditioning to a supported `sigA` source; external trigger input 0 with `-selA 2` avoids the persisted AUX-direction setting
* AD5693 DAC on I2C bus 1 at address `0x4c`, such as the DAC on [PP_PMOD](pp_pmod_reference.md), connected to the tunable oscillator's control input

The implementation pairs the nth PPS event with the nth `sigA` event, so do not feed an undivided oscillator or a source with a different event rate. The released `sigA` mux does not include `EXT_CLKp`, and the timestamp counter runs from `core_clk`, not the selected external streamer clock. Merely connecting an oscillator to `EXT_CLKp` therefore does not establish this loop. Record the `sigA` selector, event cadence, timestamp clock source, oscillator routing and conditioning, DAC transfer function, and an independent frequency measurement before evaluating controller behavior.

AUX0 with `-selA 3` is another possible route only after verifying that AUX0 is configured as an input. Neither `ppgpsdo` nor `ppts` changes AUX direction, and that state can persist from earlier low-level access. With the external source disconnected, `ppreset -i 0x0` restores the reset-default AUX input direction before connection.

Command-line switches:

Timestamp routing and run control:

* ``-pps_in``: use the external PPS input for the PPS timestamp stream
* ``-pps_xtal``: use the crystal-derived PPS source for the PPS timestamp stream
* ``-selA N``: select the source routed to the secondary ``sigA`` timestamp stream
* ``-timeout T``: timeout for waiting on new timestamp samples; ``0`` disables timeout protection
* ``-nr N``: number of timestamp samples to read per stream; ``0`` means run continuously

PID and filtering:

* ``-kp``: proportional gain, default ``0.01``
* ``-ki``: integral gain, default ``0.1``
* ``-dp``: proportional deadband, default ``0``
* ``-di``: integral deadband, default ``0``
* ``-eps``: leaky-integrator epsilon, default ``0.0``
* ``-clip N``: clip accepted timing-error deltas to ``+/-N`` before averaging, default ``1000``
* ``-reject N``: reject timing-error deltas with magnitude greater than or equal to ``N``, default ``10000``
* ``-avg N``: average ``N`` accepted deltas before updating the PID/DAC output, default ``1``; must be greater than zero

`-clip`, `-reject`, `-dp`, and `-di` operate on raw `core_clk` timestamp-counter ticks, and the PID gains act on that tick-domain error. Their physical-time meaning therefore changes with `core_clk`; record its measured frequency with every set of controller settings.

DAC output mapping:

* ``-k K``: intercept for converting PID control value to DAC voltage, default ``2.6``
* ``-l L``: slope for converting PID control value to DAC voltage, default ``-0.01``
* ``-vmin V``: minimum DAC output voltage after clamping, default ``0.0``
* ``-vmax V``: maximum DAC output voltage after clamping, default ``5.0``

Controller updates use `voltage = k + l * control`, clamped to `vmin` through `vmax`. The current verbose settings line labels the coefficients in the opposite algebraic order; the expression here follows the implemented calculation.

`ppgpsdo` always reads both the PPS and ``sigA`` timestamp streams and pairs samples from those two paths.

## Hardware side effects

On every invocation, `ppgpsdo` opens I2C bus 1 at address `0x4c`, configures the DAC for gain 2 with its internal reference enabled, and immediately writes `2.6 V`. This initial write occurs before timestamp reads and is not passed through `-vmin` or `-vmax`. Later accepted controller updates use the configured conversion and clamp. The command does not restore the previous DAC value on exit; the last programmed voltage remains in place.

Implementation notes:

* timestamp capture and pairing live in [`c++/pptool_measurement.cc`]({{ source_file("c++/pptool_measurement.cc") }})
* timestamp routing comes from [`c++/timestamp.hh`]({{ source_file("c++/timestamp.hh") }})
* DAC control is handled through the I2C-backed helper used in the same command implementation

See also [PP_PMOD hardware reference](pp_pmod_reference.md).

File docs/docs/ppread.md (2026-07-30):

## ppread

`ppread` is a qualified-sample readback capture tool. It can dump captured run-length-encoded data to console,
or it can switch into export mode and save the capture in the [PulsePins text sequence format](sequence_format.md), as a VCD projection,
as a current-build binary sequence snapshot, or as any combination of those.

Files exported by `ppread` can be replayed with [`ppplay`](ppplay.md). VCD exports use the
default `outs` signal and `$timescale 10ns`, matching `ppplay`'s default VCD target and scale.
All exports represent only samples for which `qout_valid` was high, not the authored operators or control flow. Readback flushes a run when validity drops but records no duration for the invalid interval, so no-strobe states and trigger, gate, or idle gaps are absent from replay. The binary snapshot preserves normalized current-width captured elements and a force-trigger flag, which `ppread` writes as false, but loading requires matching control, count, value, and trigger widths and execution still depends on external hardware context.

Command line arguments:

* ``-oe``: physical output enable (bool). If true, we are reading internally generated data. If false, we are
reading external data on the target-board I/O pins. If unspecified, leave the current hardware setting
unchanged; after reset the default is false.
* ``-timeout``: controls readback idle wait bounds. If omitted, `ppread` uses a conservative default timeout: 2 s waiting for the first readback element and 2 s for later idle gaps. A positive value is interpreted as time after the last element read. ``-timeout 0`` disables idle-timeout protection. For compatibility, a negative value is interpreted as a total timeout from the start of the current readback phase, in seconds; prefer ``-hard-timeout`` for new commands.
* ``-hard-timeout T``: total timeout from the start of the current readback phase. Time units such as ``ms``, ``s``, and ``min`` are accepted. This bounds the readback phase, not setup or sequence transmission that occurs before it.
* ``-save-vcd <file>``: capture the qualified readback runs and project them into a VCD file. The default C++ VCD export uses ``$timescale 10ns`` so captures replay through ``ppplay`` with its default VCD scale.
* ``-save-text <file>``: capture the qualified normalized runs in PulsePins text sequence format.
* ``-save-binary <file>``: save the captured `Sequence` as a current-build binary snapshot.

If any of ``-save-vcd``, ``-save-text``, or ``-save-binary`` is specified, `ppread` switches into export mode: it captures
the readback stream into a `Sequence`, writes the requested file(s), and prints a concise summary
instead of dumping every captured run to the terminal.

A timeout does not force the hardware encoder to flush its active run. A run becomes available only when the value changes, its counter saturates, or `qout_valid` drops. Consequently, a constant valid level can produce an empty bounded capture, and the run active at timeout is omitted. Arrange a validity drop or value transition when the final run must be saved.

## Examples

Bound the readback phase to one second and save completed runs as VCD:

```bash
ppread -hard-timeout 1s -save-vcd capture.vcd
```

Bound the readback phase to one second and save completed runs as PulsePins text:

```bash
ppread -hard-timeout 1s -save-text capture.seq
```

Save both formats at the same time:

```bash
ppread -hard-timeout 1s -save-vcd capture.vcd -save-text capture.seq
```

Save a current-build binary snapshot:

```bash
ppread -hard-timeout 1s -save-binary capture.ppbin
```

### Record and replay

Follow the [capture and replay procedure](manual/capture_replay.md). Use two board terminals: start `ppread -veryverbose ...` in the foreground in terminal 1 and wait for its initial `Readback status:` line before starting the waveform source in terminal 2. Do not background `ppread` or substitute a guessed sleep for that readiness check.

Use `capture.vcd` when you want waveform viewing as well as replay, `capture.seq` when you want
an editable normalized text sequence, and `capture.ppbin` when you need a matching-build snapshot
of the qualified captured `Sequence`. None of these restores authored control flow, invalid gaps,
or no-strobe states. An unmodified capture has no trigger records and its force flag is false, so
replay it with `-force`. To wait for a configured condition, add trigger records to a text sequence
rather than only omitting `-force`.

`ppread` captures only samples produced while it is active. It cannot recover a finite waveform that completed before the readback encoder was reset at command startup.

When `-oe 0` is used, this becomes a simple external logic-analyzer capture workflow for the
`qout` bus and `qout_valid` sample qualifier.

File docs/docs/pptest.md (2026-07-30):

## pptest

``pptest`` is a tool for running a range of test protocols. Using the readback interface, it allows you to perform
self-tests of the entire pulse generation system, including the advanced triggering. The source code of ``pptest``
also serves as an example of the API use, as it covers most of the elementary use cases.

### pptest syntax

The basic syntax is

```pptest <nr> [args...]```

``nr`` indicates the test number.

Command line switches:

* ``-c``: number of counts (or the overall scale of counts)
* ``-v``: output data value (or a range of values, or the maximal value in randomized sequence generation)
* ``-trig``: perform the triggering sequence (subset of tests)
* ``-p``: trigger pattern
* ``-m``: trigger mask
* ``-t``: final data value
* ``-random_final``: append a random final data value instead of the default no-modify final terminator
* ``-check``: perform verification using the readback method
* ``-timeout``: controls readback wait bounds during ``-check`` and ``-read``; if omitted, the default is a conservative 2 s timeout both for the first readback element and for later idle gaps. Use a positive value for idle-gap timeout, or ``-timeout 0`` to disable idle-timeout protection. For compatibility, a negative value is interpreted as a total timeout from the start of the current readback phase, in seconds.
* ``-hard-timeout T``: total timeout from the start of the current ``-check`` or ``-read`` phase. Time units such as ``ms`` and ``s`` are accepted. This is preferred over negative ``-timeout`` values for new commands.
* ``-dont_wait``: return after queueing the sequence, activating or arming the trigger, and completing any requested readback phase. This skips the normal wait and post-run cleanup, so forced or armed trigger state may remain active until reset, reconfiguration, or explicit deactivation.
* ``-dump-converted``: dump out the sequence of elements after converting elements with non-trivial update modes to simple BITLOAD elements
* ``-i``: initial value to be presented on the output ports before the sequence begins to stream out
* ``-core_pll``: configure the core/control-side PLL using a preset name, strict raw ``N,M,C`` string, or calculated frequency string
* ``-core_pll_charge_pump``: set the core PLL charge pump parameter
* ``-core_pll_bandwidth``: set the core PLL bandwidth parameter
* ``-int_pll``: configure the internal candidate streamer-clock PLL using a preset name, strict raw ``N,M,C`` string, or calculated frequency string
* ``-int_pll_charge_pump``: set the internal PLL charge pump parameter
* ``-int_pll_bandwidth``: set the internal PLL bandwidth parameter

Tests return code 0 if successful. Non-zero return codes use the shared [PulsePins return-code bits](return_codes.md). Finite playback runs also have an internal streamer-completion timeout: if the streamer reports neither clean `done` nor `buffer_error` within 10 s, the tools report `timed out waiting for streamer completion (10 s internal limit)` and skip the usual post-completion checks.

If neither ``-t`` nor an explicit ``final V`` sequence record is provided, the shared playback path appends a no-modify final terminator. The outputs therefore remain at the last value produced by the sequence. Set ``-random_final`` or the environment variable ``PP_RANDOM_FINAL`` to request a random final value.  ``-t``, ``-random_final``/``PP_RANDOM_FINAL``, and an authored ``final V`` record are mutually exclusive final-output selections.

### Integer parameter parsing

The numeric parameters can be expressed in decimal (42), hexadecimal (0x2A), octal (052) or binary (0b101010). The
parser is implemented in [`tidbit/misc.hh`]({{ source_file("tidbit/misc.hh") }}). Look for functions ``parse_uint8_t``, ``parse_uint32_t`` and
``parse_uint64_t``. Underscores are ignored; this allows large input values to be easier to read, e.g. 1_000_000_000.
Finally, SystemVerilog-style integer literals are also parsed correctly (e.g. ``8'b1111_1111``, ``32'hFF_FF_FF_FF``, ``4'hff`` and similar). Sized literals are evaluated at their declared width, so ``4'hff`` is truncated to ``0xf``. Unknown/high-impedance digits such as ``x``, ``z``, and ``?`` are accepted by the low-level literal parser but rejected by ordinary unsigned CLI parameter conversions.

WARNING: be careful not to use a leading 0 in what is intended to be a decimal number, because
the string will be parsed as an octal base representation.

### PLL settings

The PLL input clock is a 50 MHz signal generated by a crystal oscillator on the DE10-Nano board. The default frequencies are 100 MHz for both `core_clk` and `int_clk`. The two PLL wrappers are configured separately:

* ``-core_pll`` / ``-core_pll_charge_pump`` / ``-core_pll_bandwidth`` for `core_clk`
* ``-int_pll`` / ``-int_pll_charge_pump`` / ``-int_pll_bandwidth`` for `int_clk`

Each PLL profile may be given as a raw ``N,M,C`` string, as one of the symbolic presets from
[`c++/pll_rules.hh`]({{ source_file("c++/pll_rules.hh") }}), or as a frequency string such as ``66M``. Presets and raw triplets must satisfy the same strict Cyclone V `fPFD` and `fVCO` limits used by [`pllcalc`](pllcalc.md). If a value is neither a preset nor raw parameters, the runtime uses the same Cyclone V PLL calculator, prints a warning with the calculated parameters, and then programs the PLL.

## pptest test cases

### Test 1

Empty sequence (i.e., terminator element only). This can be used for testing final data value setting using the
``-t`` switch, or randomized final values using ``-random_final``/``PP_RANDOM_FINAL``.

### Test 2

Sequence with a single element. Value and count can be specified using ``-v`` and ``-c``.

### Test 3

Counter: step up from a value specified by ``-v0`` (included) to a value specified by ``-v`` (excluded). Fixed number of counts
for each value (set by ``-c``).

### Test 4

Counter with a random number of counts. If ``-rnd`` is specified, the values are randomized, too.

### Test 5

Test for elements that suppress the `qout_valid` sample qualifier and `qout_strobe` sampling pulse (three elements, one with both signals suppressed).

### Test 6

Bitwise update mode test on a short sequence.

### Test 7

Initial value test. Defaults to 4, use ``-iv`` to override. The switch ``-ns`` furthermore adds an initial element with the same value but without the `qout_valid` sample qualifier or `qout_strobe` sampling pulse.
This can be used in combination with ``-timeout`` and ``-dont_wait`` to perform a self-test
of the initial value setting; remember that ``-dont_wait`` intentionally leaves normal post-run cleanup to a later reset,
reconfiguration, or explicit deactivation.

### Test 8

Fully randomized sequence testing (random values, random counts, random update operations).

### Test 9

Test qout_override functionality: sends out a sequence, checks the final qout value, then overrides it with a different
value.

### Test 10

Test of the preprocessor (replay generator). Sequence defined using ``-c`` and ``-v``. The repetitions are defined
using ``-repetitions``. There can be multiple replays, controlled using ``-nr_replays``.
Additional single elements can be added using ``-pre``, ``-mid`` and ``-post`` (lengths defined by ``-p``, ``-m``
and ``-o`` respectively).

### Test 11

Test infinite replay. This generates a periodic signal.

### Test 12

Simple trigger (defaults to bit 0 high; pattern and mask can be overridden using ``-p`` and ``-m``), one-element
sequence. If ``-trig`` is specified, the tool will generate the trigger signal using the internal PIO interface for
trigger testing. Without this switch, the trigger must be provided through an external signal.

### Test 13

Two-step trigger sequence. The first condition defaults to 01 (can be overridden using ``-p`` and ``-m``), the second
one to 10 (can be overridden using ``-r`` and ``-n``). The correct trigger sequence can be emitted using ``-trig``.

### Test 14

Multistage triggering test: the triggering sequence is a series of two different patterns and
masks, specified by ``-p`` and ``-m`` (the default is pattern=01 and mask=01) and by ``-r`` and
``-n`` (the default is pattern=10 and mask=10). The data sequence consists of a single symbol.

Additional parameters:

* ``-cycles``: number of such two-step trigger units
* ``-delay``: time delay between each trigger signal in microseconds, for testing with ``-trig``;
default is 10000 (10 ms)

### Test15

Test for retriggering. It alternates between two trigger conditions, one set by ``-p``, ``-m`` and
another set by ``-r`` and ``-n`` pair.

Additional parameters:

* ``-cycles``: number of alternating retrigger stages
* ``-delay``: time delay between each trigger signal in microseconds, for testing with ``-trig``; default is
100000 (100 ms)
* ``-r``: second trigger pattern
* ``-n``: second trigger mask

### Test 19

Pseudorandom generator (xoroshiro128+) test. If ``-c`` value is larger than 0, a given number of
random variates is produced and output on all 32 output lines. If ``-c`` value is zero, an
infinite stream is generated.

### Test 20

Continuous test. Starts up two threads, one filling the decoder queue, one reading back from the readback encoder.
The two are compared in real time. If ``-v`` is zero, the test runs indefinitely. If ``-v`` is finite, the value
counts up from zero to this maximum value (excluded).

Additional parameters:

* ``-quiet``: do not dump each element
* ``-rnd``: randomize values
* ``-report N``: report statistics at most every N seconds; this shows total run time, the total number of elements (size), and the total duration of the sequence so far (length)

### Test 21

[Pmod DA3](https://digilent.com/shop/pmod-da3-one-16-bit-d-a-output/) SPI sweep. This generates DAC codes for a Pmod DA3 module using the C++ [SPI sequence generator](cpp.md#spi-sequence-generation) and streams them through PulsePins.

By default the test sweeps from 0.0 V to 2.5 V in 0.01 V increments, uses a 10 MHz SPI clock, and inserts a 10 ms dwell after each DAC update. This produces a sweep of roughly 2.5 s total duration.

Additional parameters:

* ``-vmin``: starting voltage, default 0.0
* ``-vmax``: ending voltage, default 2.5
* ``-vstep``: voltage increment, default 0.01
* ``-dwell``: dwell time after each DAC update, default ``10ms``
* ``-spi_clock``: requested SPI clock frequency in Hz, default ``10e6``

### Test 42

Stream out a sequence from the text file supplied with ``-f``. The accepted records and numeric syntax are defined by the [PulsePins text sequence format](sequence_format.md).

Invoke it as ``pptest 42 -f FILE``. Here ``-f`` selects the file, while an ``f`` record inside the file requests forced triggering. Test 42 uses the shared final-output policy: ``-t``, ``-random_final``/``PP_RANDOM_FINAL``, and a terminal ``final V`` record are mutually exclusive; if none is selected, playback appends a no-modify final terminator.

## ppmstest

Tool for testing multistreamer.

### Test 1

The combiner mode is set with ``-mode``. The expected result is computed and compared with what
is actually read back.

## ppdmatest

Tool for testing streaming sequences from a RAM buffer using direct memory access.

### Test 4

Same as test 4 in pptest, but using DMA for the data transfer.

### Test 21

Test for a large number of elements. Note that the readback test is not performed here; this test
only exercises memory transfers, and no correctness testing of the generated bit pattern is implemented.

### Test 22

Repeated playback of the long DMA sequence from test 21. The number of repetitions is controlled by ``-reps``; ``0`` means repeat indefinitely. Finite playback appends a terminator after the final repeated sequence so the streamer exits cleanly.

### Test 25

Pmod DA3 sine generator using DMA. This builds one sampled sine-wave period as a sequence of SPI DAC updates for the [Pmod DA3](https://digilent.com/shop/pmod-da3-one-16-bit-d-a-output/) and then replays that period using DMA, so repeated playback produces a continuous periodic waveform.

Additional parameters:

* ``-samples``: number of DAC updates per sine period, default ``250``
* ``-reps``: number of DMA repetitions, default ``0`` for infinite playback; finite playback appends a terminator after the final repeated period so the streamer exits cleanly
* ``-dwell``: hold time after each DAC update, default ``10us``
* ``-vmin``: minimum sine voltage, default ``0.0``
* ``-vmax``: maximum sine voltage, default ``2.5``
* ``-spi_clock``: requested SPI clock frequency in Hz, default ``10e6``

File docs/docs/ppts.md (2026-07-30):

# ppts

`ppts` reads timestamp events from the `ts_core` hardware block. It is useful for checking that an event source is present, estimating event periods from timestamp differences, and validating selector routing before using higher-level timing tools.

For the underlying capture architecture, see [Timestamp capture](timestamp.md).

The tool uses the shared startup path, configures the timestamp-routing PIO, clears the timestamp FIFOs and overflow state after routing is selected, and then starts one reader thread per enabled timestamp stream.

The implementation lives in [`c++/pptool_measurement.cc`]({{ source_file("c++/pptool_measurement.cc") }}) and uses the timestamp interface from [`c++/timestamp.hh`]({{ source_file("c++/timestamp.hh") }}).

### Syntax

```bash
ppts [options]
```

### Stream selection

By default `ppts` reads the (pulse per second) PPS stream.

Use these switches to control which streams are enabled:

* `-nopps`: disable PPS capture entirely
* `-sigA`: enable the secondary `sigA` stream

This means the most common modes are:

* PPS-only capture
* `sigA`-only capture using `-nopps -sigA`
* simultaneous PPS + `sigA` capture using `-sigA`

Common options:

* `-nopps`: disable PPS capture
* `-sigA`: enable capture on the `sigA` path
* `-selA N`: select the source routed to `sigA`
* `-pps_in`: use the external PPS input
* `-pps_xtal`: use the crystal-derived PPS source
* `-timeout T`: timeout for waiting on new timestamp samples
* `-nr N`: stop after a limited number of samples; `0` means run continuously
* `-ignore_ts_overflow`: continue reading even if `ts_core` reports timestamp overflow

The `-nr` limit is applied per active stream reader.

### `sigA` Sources

The `sigA` stream is a secondary timestamp path with a selectable source. The selector values are documented here; the lower-level routing model is described in [Timestamp capture](timestamp.md).

| `-selA` | Source | Typical Use |
|---:|---|---|
| `0` | Streamer trigger activated | Timestamp when the streamer trigger logic fires. |
| `1` | Streamer trigger input 0 | Observe trigger input 0 at the streamer trigger block. |
| `2` | External trigger input 0 | Observe external trigger input 0. |
| `3` | Auxiliary input 0 | Observe AUX input 0. |
| `4` | 1 s generated pulse | Check timestamp cadence against a slow internal source. |
| `5` | 100 ms generated pulse | Check 10 Hz internal timing. |
| `6` | 10 ms generated pulse | Check 100 Hz internal timing. |
| `7` | 1 ms generated pulse | Stress-test 1 kHz internal timing; use `-ignore_ts_overflow` when overflow is expected. |

If `-selA` is omitted, selector `0` is used.

### PPS Sources

The PPS path has a separate two-way source selector:

| Option | PPS Source |
|---|---|
| `-pps_xtal` | crystal-derived PPS source |
| `-pps_in` | external PPS input |

After reset, the hardware default is the crystal-derived PPS source. If both `-pps_in` and
`-pps_xtal` are omitted, `ppts` leaves the current PPS selector unchanged.

If both `-pps_in` and `-pps_xtal` are supplied, the later command-handler check selects `-pps_xtal` because `ppts` applies `-pps_xtal` after `-pps_in`.

### Output format

`ppts` prints lines of the form:

* stream label (`PPS` or `sigA`)
* wall-clock timestamp
* sample counter
* captured timestamp value
* difference from the previous sample on the same stream

The difference field is empty for the first sample and populated afterwards.

Output behavior:

* PPS samples are printed with the label `PPS`
* auxiliary samples are printed with the label `sigA`
* the default formatted output includes the sample counter, the timestamp value, and the difference from the previous sample

If both paths are enabled, the tool reads them concurrently using separate threads.

Because the two streams are read independently, the printed lines from PPS and `sigA` may interleave.

Because the hardware capture core has one pending slot per path and reports overflow if later events arrive before that slot is accepted, `ppts` is intended for sparse timing signals rather than dense pulse trains.

By default, timestamp overflow is reported as a command failure. Use `-ignore_ts_overflow` for deliberate stress tests or fast generated sources where dropped timestamp events are expected and the goal is to inspect the samples that software did receive.

Use [Timestamp capture](timestamp.md) for counter-width, edge-capture, FIFO, and timing-semantics details.

### Typical examples

Read PPS timestamps continuously:

```bash
ppts
```

Read five samples explicitly from the external PPS input, with a finite wait bound:

```bash
ppts -pps_in -nr 5 -timeout 2
```

Read up to 10 samples from external trigger input 0 through `sigA` selector `2`, stopping if a sample wait times out:

```bash
ppts -nopps -sigA -selA 2 -nr 10 -timeout 2
```

Read only the `sigA` stream from the generated 1 s pulse:

```bash
ppts -nopps -sigA -selA 4 -nr 5 -timeout 2
```

Before connecting an external source to AUX0 for `-selA 3`, verify that AUX0 is configured as an input. Neither `ppts` nor `ppaux` changes AUX direction, and low-level settings can persist; with the source disconnected, `ppreset -i 0x0` restores the reset-default input direction.

Read both streams and stop after 10 samples per stream:

```bash
ppts -pps_xtal -sigA -selA 4 -nr 10 -timeout 2
```

Read the fast 1 ms generated `sigA` source without failing on expected timestamp overflow:

```bash
ppts -nopps -sigA -selA 7 -nr 10 -timeout 10 -ignore_ts_overflow
```

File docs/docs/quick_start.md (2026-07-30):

# Quick start

This is the shortest path from a released SD-card image to a validated DE10-Nano and a first digital output.

**Version note:** this manual follows the current source tree and can be newer than the latest published binary image. Check the selected release notes for its included commands. If a documented command is missing, use documentation from that release or deploy a matching current-source build.

The example-led [User manual](examples.md) targets current `main` and host/FPGA ABI 6. Follow those chapters only with a matching host build and FPGA image.

## What you need

* a DE10-Nano with its power supply
* a microSD card and card reader
* Ethernet access, or a USB mini cable for the UART console
* optionally, an oscilloscope or logic analyzer for observing the first output

No shield or external wiring is required for the baseline self-test.

## 1. Download and flash the image

Download the latest binary SD-card image from the [PulsePins releases page](https://github.com/rokzitko/PulsePins/releases).

Write the image to the microSD card with a tool such as BalenaEtcher, Raspberry Pi Imager, or Rufus. Insert the card into the DE10-Nano before applying power.

## 2. Boot and find the board

Connect Ethernet and power on the board. The released image requests an address using DHCP. Its default Ethernet MAC address is `D6:7D:AE:B3:0E:BA`.

Find the assigned address in your router's DHCP lease list. If Ethernet is unavailable, connect through the USB mini port marked `UART`; the [hardware setup](getting_started_hardware.md) page covers the fallback path and board-access details.

## 3. Log in

Connect over SSH, substituting the board's address:

```bash
ssh root@BOARD_IP
```

The released image initially uses:

* user: `root`
* password: `eit`

Change the default password before placing the board on an untrusted network:

```bash
passwd
```

You can also install your public SSH key with `ssh-copy-id root@BOARD_IP` from your development machine.

## 4. Validate the baseline image

Disconnect external circuits from the PulsePins output, valid, and strobe pins, or first verify that they can safely accept generated 3.3 V patterns. The self-tests enable the output drivers and exercise nonzero values even though they do not require external loopback wiring.

On the board, run:

```bash
run_all_tests
```

The command should exit successfully and print `SUCCESS`. At the default 100 MHz streamer clock, a full run currently takes about seven minutes. It uses the FPGA readback path for internal comparison.

If the check fails, keep the complete output and continue with [Testing procedures](testing.md).

## 5. Generate a first output

PulsePins uses 3.3 V LVTTL signals. Disconnect equipment that must not be driven, then use the [DE10-Nano signal reference](de10_nano_reference.md) or the [PP_PMOD hardware reference](pp_pmod_reference.md) to connect `qout[0]` and ground to a high-impedance scope or logic-analyzer input. Do not apply a direct 50 ohm termination to an unbuffered FPGA pin.

Generate ten 10 ms periods on `qout[0]`, returning the bus to zero afterward:

```bash
ppfg -burst 10 -period 10ms -trig -v1 0x1 -v0 0x0 -t 0x0
```

Expect ten 50% duty-cycle pulses on `qout[0]`; the other output bits remain low. `ppfg` can return to the shell before the hardware burst finishes, so observe the complete ten-period burst rather than treating the prompt as completion. The final value is zero, but the output drivers remain enabled. Follow the [manual cleanup](manual/first_output.md#cleanup) before connecting another driver.

## Optional burn-in

For a longer board check, run:

```bash
run_all_tests_forever
```

The runner stops at the first failed sweep. Current-source builds write summary and per-run logs under `/var/volatile/pulsepins-test-logs`; older images may differ. See [Testing procedures](testing.md) for current log details and reporting options.

## Where to go next

* [Choose the right tool](choose_tool.md) for a task-to-interface map
* [User manual](examples.md) for finite, source-reviewed laboratory workflows
* [Sequencer model](sequencer_model.md) for the data and trigger model
* [Hardware setup](getting_started_hardware.md) for board access and optional hardware
* [Python API](python.md), [C++ API](cpp.md), or [SCPI server](ppscpi.md) for automation

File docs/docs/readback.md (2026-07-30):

# Readback

Readback is the name of the run-length encoder subsystem connected directly to the PulsePins streamer output.

Its job is to observe streamed symbols, compress them back into `{count, value}` runs, and expose those runs to software for verification, debugging, and external-signal capture. PulsePins uses this path heavily for self-test: software can compare the observed output stream against the reference sequence sent to the streamer.

Besides verification, the readback path lets PulsePins act as a qualified-sample digital logic analyzer: it can observe activity while `qin_valid` is asserted, compress those samples on-chip, and export the captured runs as a VCD file for standard waveform viewers.

The acquired sequence uses the same top-level element format as the streamer (`control`, `counter`, `value`), but in practice the control field is always zero and software interprets the readback as plain `BITLOAD` output states.

The bus widths in [`ip/rl_encoder_if/rl_config.vh`]({{ source_file("ip/rl_encoder_if/rl_config.vh") }}) need to match those in [`ip/streamer/config.vh`]({{ source_file("ip/streamer/config.vh") }}).

For a maintainer-oriented RTL map, see [`ip/rl_encoder_if/README.md`]({{ source_file("ip/rl_encoder_if/README.md") }}).

## Architecture overview

At a high level the flow is:

1. sampled output values arrive on `qin`
2. [`rl_encoder.sv`]({{ source_file("ip/rl_encoder_if/rl_encoder.sv") }}) groups consecutive equal samples into runs
3. a dual-clock FIFO buffers those runs for ARM-side reads
4. [`rl_encoder_if.sv`]({{ source_file("ip/rl_encoder_if/rl_encoder_if.sv") }}) exposes the encoded runs on Avalon-ST and adds control/status registers
5. [`c++/readback.hh`]({{ source_file("c++/readback.hh") }}) either dumps the captured stream or compares it against a reference `Sequence`

This makes the readback path the main comparison path between the generated FPGA output and the control-software model.

## `rl_encoder` core

Inputs:

* `qin`: observed data word, usually connected to streamer `qout`
* `qin_valid`: sampled-data validity qualifier
* `qin_clk`: sampled-data clock
* `qin_strobe`: strobe signal retained for the dormant `WEIRD_CLOCK` alternate mode

Important behavior:

* equal consecutive samples are merged into one run-length element
* normal builds sample `qin` on `qin_clk` while `qin_valid` is asserted
* the strobe-clocked alternate mode is hidden unless the RTL is explicitly built with `WEIRD_CLOCK`
* when validity drops, the pending run is flushed so the final observed state is not lost
* the encoder does not record the duration of a low-validity interval; playback therefore compresses invalid gaps and omits no-strobe states
* a software timeout does not flush the active hardware run, so a constant valid level can leave no completed run to export and the run active at timeout is omitted
* overflow latches high if software is not draining the encoded FIFO fast enough

For readback sampling and FIFO latency notes, see [RTL latency and timing](latency.md).

## rl_encoder_if interface

[`rl_encoder_if.sv`]({{ source_file("ip/rl_encoder_if/rl_encoder_if.sv") }}) provides:

* Avalon-ST output carrying encoded readback elements
* Avalon-MM control/status for reset, active-mode status, FIFO-empty state, overflow, observed pulse count, and CRC32

The pulse counter and CRC are computed in the sampled-input domain, which lets software compare transport-level integrity against the transmitted reference stream.

## CRC32 integrity checks

PulsePins uses a streaming [cyclic redundancy check](https://en.wikipedia.org/wiki/Cyclic_redundancy_check) as a compact integrity check over the output words observed by the streamer and readback paths. A CRC is an error-detection value, not a cryptographic hash; here it is used to catch accidental data-path divergence alongside full readback comparison, FIFO accounting, overflow checks, and final-output checks.

The RTL helper [`ip/misc/crc32.sv`]({{ source_file("ip/misc/crc32.sv") }}) implements reflected CRC-32/Ethernet-style processing over 32-bit words: LSB-first, polynomial `0xEDB88320`, initial state `0xffffffff`, and final XOR `0xffffffff`. For CRC parameter naming, the [CRC RevEng catalogue](https://reveng.sourceforge.io/crc-catalogue/all.htm#crc.cat.crc-32-iso-hdlc) is a useful reference.

During post-run checks, software compares the streamer-side CRC with the readback-side CRC. A mismatch means the transmitted stream and observed stream disagree at the compact integrity-check level and sets `RC_ERROR_CRC_MISMATCH`; it does not by itself identify which word differed.

## Software interface

The software interface is provided through class `readback` in [`c++/readback.hh`]({{ source_file("c++/readback.hh") }}).
The key member functions are:

* `reset`: reset the encoder and discard stale FIFO contents
* `clear_fifo`: read and discard all queued elements
* `filled`: report whether encoded elements are available
* `check_fill_status`: print FIFO status/debug information
* `read`: read one encoded element
* `read_all`: dump the captured stream until timeout or external termination
* `check`: compare the captured stream against a reference `Sequence`

Captured deterministic waveforms can also be turned into VCD files through the `Sequence` export path in [`c++/sequence.hh`]({{ source_file("c++/sequence.hh") }}).

At the CLI level, `ppread` can save captures as canonical PulsePins text sequences, VCD projections of the qualified runs, or current-build `.ppbin` snapshots. See [Representation fidelity](sequence_format.md#representation-fidelity) for the boundaries of each export.

The `check` function returns true if no errors are detected. A timeout argument can be provided; if no new elements are received during the specified interval, an exception is raised. Higher-level playback tools use conservative defaults when no timeout is provided: 2 s waiting for the first readback element and 2 s for later idle gaps. An exception is also raised if the reference sequence is exhausted and a new element is received from the encoder. A report is produced when the check completes, including the number and ratio of errors plus the difference in encoded size and effective output length.

## Readback of external signals

If the physical output enable ``oe`` is low, the readback core is reading signals from the external
pins, i.e. the 32 `qout` pins actually act as inputs, and the `streamer_qout_valid` pin starts
acting as the `qout_valid` qualifier input port. The [ppread](ppread.md) tool can be used to read the
generated data stream. One application of this tool is to troubleshoot another PulsePins board
by connecting the qout and qout_valid ports together and clocking both devices from the same clock
source. In this mode, PulsePins effectively becomes a simple external digital logic analyzer for
the qout bus and `qout_valid` qualifier.

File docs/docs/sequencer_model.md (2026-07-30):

# Sequencer model

PulsePins turns compact sequence elements into deterministic digital output updates. This page describes the model shared by the command-line tools, C++ and Python APIs, and FPGA streamer.

For the RTL implementation, register map, and clock-domain details, continue with the [Streamer subsystem](streamer.md), [Implementation details](details.md), and [Clock domains](clock_domain.md).

## Data path and run-length encoding

[Run-length encoding](https://en.wikipedia.org/wiki/Run-length_encoding) (RLE) stores a stable output value as a value and a repetition count instead of recording one sample per clock. A regular element with count `N` holds its output value for `N` streamer-clock cycles.

The HPS sends encoded elements through an Avalon-ST input path. The FPGA classifies and decodes those elements, crosses the decoded updates into `streamer_clk` through an output FIFO, and advances the output after the configured trigger fires and while the gate is open. The readback path can encode the emitted samples again for verification or capture.

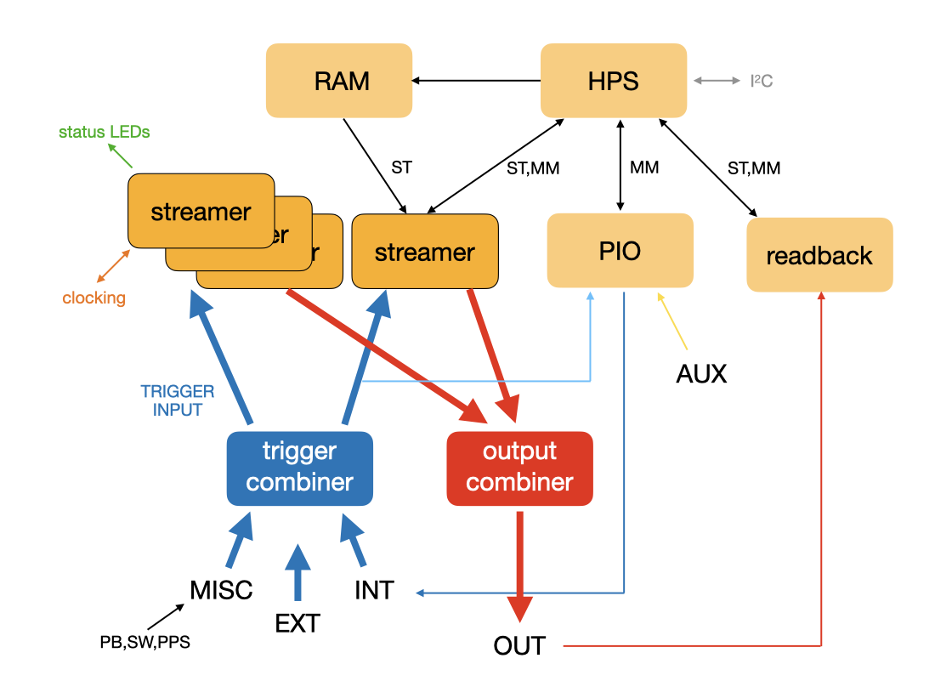
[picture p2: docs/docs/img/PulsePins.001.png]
PulsePins data path


HPS means hard processor system (ARM cores), ST means [Avalon-ST](https://www.intel.com/content/www/us/en/docs/programmable/683091/22-3/avalon-streaming-interfaces.html), MM means [Avalon-MM](https://www.intel.com/content/www/us/en/docs/programmable/683091/22-3/avalon-memory-mapped-interfaces.html), and PIO means programmable input/output.

## Sequence elements

Each element contains three 32-bit values in the released DE10-Nano build:

* `control_t y`: control parameter
* `count_t c`: run length, replay count, or other count payload
* `value_t v`: output value, replay length, or packed trigger payload

The standard transport order is control, count, value. Matching RTL and software builds can use different data or count widths.

The user-facing [PulsePins text sequence format](sequence_format.md) represents a normalized subset of this model rather than arbitrary raw element triplets.

The control parameter is defined in [`ip/streamer/config.vh`]({{ source_file("ip/streamer/config.vh") }}):

| Name | Bit | Meaning |
| ---- | --- | --- |
| `BIT_TRIGGER` | 0 | regular element (`0`) or trigger element (`1`) |
| `BIT_TRIGGER_FINAL` | 1 | intermediate or final trigger stage |
| `BIT_TERMINATE` | 2 | sequence terminator |
| `BIT_NO_STROBE` | 3 | suppress `qout_valid` and `qout_strobe` |
| `BIT_MODE*` | 4-7 | load, set, clear, flip, invert, shift, and other update modes |
| `BIT_NOPASS` | 8 | pass directly or send through the preprocessor |
| `BIT_STORE` | 9 | store an element in preprocessor memory |
| `BIT_POSITIONS*` | 10-12 | preprocessor storage position in the released eight-slot build |
| `BIT_REPLAY` | 15 | replay a stored subsequence |
| `BIT_RETRIG` | 16 | request the next trigger subsequence |
| `BIT_PRNG` | 17 | emit pseudorandom values |

### Regular and final elements

A regular element specifies an output update and how long the resulting state persists. The mode bits can load a complete value or apply an operation such as set, clear, toggle, shift, AND, OR, XOR, or XNOR.

Normally a regular element asserts `qout_valid` and produces a `qout_strobe` pulse. `BIT_NO_STROBE` suppresses those qualifiers but still updates the output bus.

The final element terminates decoding and leaves its decoded value as the persistent final state. On a clean run, consuming the terminator asserts `done`. A final element is not reported as an ordinary valid output sample.

### Trigger elements

Trigger elements travel through the same input stream but are loaded into the trigger-program path rather than the normal output decoder. Each stage contains a mask and a pattern. A mask bit selects an input to test, and the corresponding pattern bit specifies the required value.

For the released 8-bit trigger bus, a trigger element sets `c` to zero and packs both fields into `v`: bits 7:0 hold the pattern and bits 15:8 hold the mask.

The released trigger-program buffer has 256 positions. A chain fires after its stages have matched in order and a final trigger stage has been reached, or after the loaded chain is exhausted.

A sequence that uses retriggering must mark the last trigger element of each trigger subsequence as final. That marker separates the trigger stages consumed before one output segment from those loaded after the retrigger element.

## Replay preprocessor

The input preprocessor provides a second level of compression. It can store up to eight elements in the released build and replay that short subsequence without sending every repetition from the HPS.

A replay count of zero repeats indefinitely. This is the mechanism used by tools such as [`ppfg`](ppfg.md) for continuous periodic output.

## Sequence delivery

PulsePins has two main delivery paths:

* HPS-driven FIFO streaming for normal interactive and generated sequences
* memory-backed DMA transfers for sequences up to 512 MB

Both paths feed the same encoded streamer model. DMA avoids HPS intervention during the transfer and is useful when quickly changing output data could exhaust the software-fed FIFO path. After output consumption has started, the output FIFO latches `buffer_error` if advancement is requested before more data or the terminator is available. Empty reads during initial FIFO priming are not treated as underruns.

## Multiple streamers and output routing

The released design contains four independent streamer instances with separate trigger programs. Their outputs feed a configurable combiner before reaching the physical output bus.

The combiner supports:

* selection of one streamer
* bitwise AND, OR, XOR, and XNOR
* per-bit majority voting
* 8-bit and 16-bit block concatenation
* sums and differences
* per-input and final-output masks, inversion, and forced values

See the [Combiner subsystem](combiner.md) for mode definitions, register behavior, and software control.

## Trigger, gate, and retrigger behavior

The trigger combiner can select or combine internal software signals, external trigger pins, and miscellaneous board signals such as push-buttons, switches, and PPS. Trigger matching is active only while trigger enable is asserted. Trigger force bypasses normal mask/pattern matching.

The main runtime controls have distinct purposes:

| Control | Effect | Resume behavior |
| --- | --- | --- |
| gate | pauses output FIFO advancement without changing trigger state | reopen the gate |
| stop | halts advancement while preserving the current stream position | clear stop if the stream remains valid |
| trigger reset | deactivates and re-arms the same active trigger stage; queued stages remain loaded | release reset and satisfy or force that stage again |
| retrigger element | completes the current trigger subsequence and waits for the next queued one | satisfy or force the next trigger stage |
| streamer reset | clears streamer and trigger FIFO state | load a new sequence |

Holding trigger reset asserted prevents triggering, including a forced trigger. None of gate, stop, or trigger reset forces `qout` to a safe value; the bus holds its last state until another element, override, or streamer reset changes it.

See [Streamer timing diagrams](streamer_timing.md) for trigger, gate, and retrigger waveforms, and [`pptrig`](pptrig.md) for source-selection diagnostics.

## Clocks and output timing

The main clocks are the 50 MHz board reference `ref_clk`, the control-side `core_clk`, the internal candidate output clock `int_clk`, and the selected `streamer_clk`. The released image normally uses 100 MHz for `core_clk` and `streamer_clk`, giving a 10 ns programmable output time step.

Decoded updates cross from the control side into `streamer_clk` through a dual-clock FIFO. `qout` updates on rising edges of `streamer_clk`; `qout_valid` qualifies ordinary output samples, and `qout_strobe` appears during the low phase of `streamer_clk`. Use one of those qualifiers to detect advancement because `qout` can hold its previous value while a gate is closed.

The selected `streamer_clk` must run continuously: output advancement, trigger state, reset synchronization, and completion all depend on it. When using an external source, establish a stable clock before selecting that path and keep it running through reset and shutdown handling.

Sampling `qout` on rising `streamer_clk` edges while `qout_valid` is high gives the receiver the normal clocked-data relationship and is preferred at higher rates. `qout_strobe` can be convenient for slower logic that needs additional hold time after the rising clock edge, but its board-level timing should be verified for the actual receiver and cabling.

The active output clock can be selected from the internal clock path or an external 3.3 V LVTTL source on `EXT_CLKp`. See [Clock domains](clock_domain.md), [RTL latency and timing](latency.md), and [Streamer timing diagrams](streamer_timing.md) before relying on cycle-level behavior.

## Output enable and readback

The 32 main output drivers default to high impedance. Setting the physical output enable `oe` lets the final combined `qout` value drive the pins. With `oe` low, the pins can instead be sampled by the readback and counter paths. The same output enable controls the bidirectional `qout_valid` and `qout_strobe` pads used by the external-capture path.

The [Readback](readback.md) subsystem re-encodes `qout_valid`-qualified samples for self-test and capture. Replay of a readback export reproduces those normalized runs rather than recovering authored operators, control flow, no-strobe states, or elapsed invalid gaps. General C++ VCD export is a flattened regular-record projection with additional [fidelity limits](sequence_format.md#representation-fidelity).

## Configurable variants

The RTL and software are structured for matching data and count widths other than 32 bits. PulsePins has been extended to 64 output channels and 64-bit counts, although only the 32-bit data/count DE10-Nano design is distributed as a prebuilt image.

The design has also been ported to an Arria 10 platform for driving 10 Gb/s transceivers on a [Terasic HAN Pilot](https://www.terasic.com.tw/cgi-bin/page/archive.pl?Language=English&No=1133), corresponding to a 100 ps unit interval. These variants require matching RTL, generated hardware, and software builds.

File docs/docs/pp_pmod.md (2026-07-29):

# PP_PMOD Reference Shield

`PP_PMOD` is the reference KiCad shield design for attaching PulsePins to the DE10-Nano GPIO headers and bringing the SoC FPGA I/O out to lab-friendly connectors.

It is an optional hardware profile rather than a required baseline. The board is intended both as a usable shield and as a starting point for derivative designs with different connectors, buffering, or peripheral choices.

## Revision and source

The top-level KiCad project is [`pcb/ppshield_pmod/shield.kicad_sch`]({{ source_file("pcb/ppshield_pmod/shield.kicad_sch") }}) with title `PP_PMOD: GPIO shield for DE10-Nano`, revision `1`, and date `2025-09-20`.

Project files:

* KiCad sources: [`pcb/ppshield_pmod/`]({{ source_file("pcb/ppshield_pmod/") }})
* Top-level schematic: [`shield.kicad_sch`]({{ source_file("pcb/ppshield_pmod/shield.kicad_sch") }})
* PCB layout: [`shield.kicad_pcb`]({{ source_file("pcb/ppshield_pmod/shield.kicad_pcb") }})

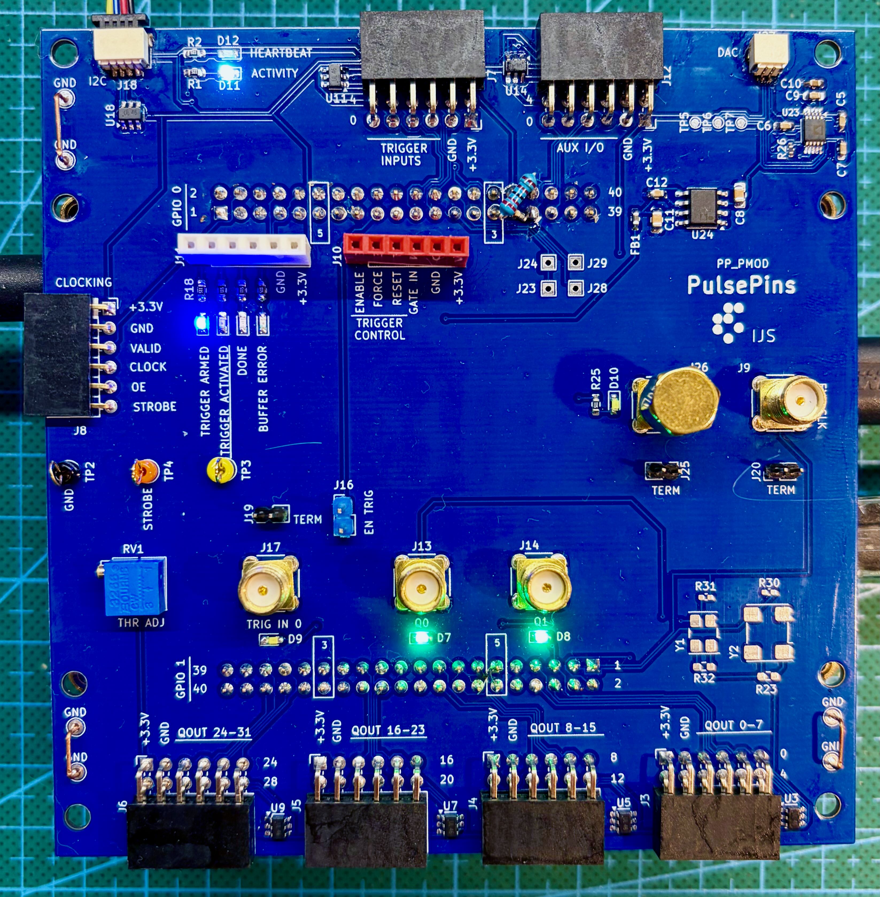
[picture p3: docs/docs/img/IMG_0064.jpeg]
PP_PMOD board


## Feature summary

The reference design includes:

* four 8-bit output connector groups carrying `Q0..Q31`
* one 8-bit auxiliary connector carrying `AUX0..AUX7`
* a trigger-input connector group plus a separate SMA trigger input path
* two buffered SMA outputs for instrument connection
* SMA inputs for `EXT_CLK` and `PPS_IN`
* a [Qwiic-compatible I2C connector](pp_pmod_reference.md#i2c-and-onboard-peripherals) for external modules
* an onboard `MCP9808` temperature sensor
* an onboard `AD5693` DAC with a separate low-noise regulator
* status, activity, and heartbeat LEDs
* test points and probe-grounding features
* optional oscillator-module footprints and optional input terminations

The `QOUT`, `AUX`, and trigger connector groups use Pmod-style 2 × 6 mechanics; for the baseline mechanical/electrical convention, see the [Pmod Interface Specification](https://digilent.com/reference/_media/reference/pmod/pmod-interface-specification-1_3_1.pdf).

All of the external connector-facing signal groups in the design are protected with ESD devices.

## Board architecture

The KiCad hierarchy is already a good map of the board:

* `GPIO` connects the shield to the DE10-Nano headers
* `QOUT` handles the main 32-bit output bus and related control/status lines
* `output buffers` drives the two SMA output channels
* `Triggering` handles trigger connectors, trigger control/status, and the thresholded SMA trigger path
* `ext_clk` handles `EXT_CLK`, `PPS_IN`, optional termination, and oscillator-module options
* `I2C` contains the Qwiic connector, onboard `MCP9808`, and onboard `AD5693`
* `AUX` brings out the auxiliary bus
* `LEDs` drives the board indicators
* `Misc` contains test points and grounding aids

## Optional features

Several parts of the board are optional or configuration-dependent:

* the onboard DAC path is optional
* the onboard temperature sensor is optional
* the oscillator footprints are optional
* some terminations are selectable or optional
* the exact shield assembly may differ from the fully populated schematic

When documenting or validating the board, record which optional parts are populated and which jumper positions are used.

## Hardware reference

All board-level connectors, timing inputs, onboard peripherals, jumpers, and test points are documented on [PP_PMOD hardware reference](pp_pmod_reference.md).

## Connector index

Quick reference for the board's main external interfaces:

| Ref | Purpose |
| --- | --- |
| `J3`-`J6` | four 8-bit `QOUT` groups |
| `J7` | 8-bit trigger input bus |
| `J8` | QOUT sideband header |
| `J9` | `EXT_CLK` SMA input |
| `J10` | trigger control header |
| `J11` | trigger/status header |
| `J12` | `AUX` bus |
| `J13` | buffered `Q0` SMA output |
| `J14` | buffered `Q1` SMA output |
| `J17` | thresholded trigger SMA input |
| `J18` | [Qwiic I2C connector](pp_pmod_reference.md#i2c-and-onboard-peripherals) |
| `J26` | `PPS_IN` SMA input |

## Example workflows

Examples worth documenting or reproducing on this board include:

* LED Pmod output checks with [`pptest`](pptest.md)
* onboard `MCP9808` reads with [`pptemp`](pptemp.md) or [`I2C/mcp9808.py`]({{ source_file("I2C/mcp9808.py") }})
* external Qwiic `TMP117` reads with [`I2C/tmp117.py`]({{ source_file("I2C/tmp117.py") }})
* DAC output checks with [`I2C/ad5693_set_vout.py`]({{ source_file("I2C/ad5693_set_vout.py") }})
* PPS validation with [`ppts`](ppts.md)
* external clock validation with [`ppfreq`](ppfreq.md)
* digital trigger-routing checks with [`pptrig`](pptrig.md)

For these workflows, record board revision, population, jumpers, external wiring, exact commands, and observed behavior.

The thresholded SMA comparator path requires setup-specific validation; record its threshold, termination, source, and observed waveform rather than assuming equivalent behavior across assemblies.

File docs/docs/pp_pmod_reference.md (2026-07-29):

# PP_PMOD Hardware Reference

This page is the compact hardware reference for `PP_PMOD`.

For board purpose, project links, and example workflows, see [PP_PMOD reference shield](pp_pmod.md).

## Conventions

The design uses 3.3 V logic on the shield-side digital interfaces.

The connector and signal names below follow the KiCad schematics. For final pin-by-pin verification, the KiCad sheets remain the source of truth.

## Connector inventory

| Ref | Interface | Type | Function |
| --- | --- | --- | --- |
| `J3` | `QOUT_0-7` | 2 × 6 right-angle socket | output bits `Q0..Q7` |
| `J4` | `QOUT_8-15` | 2 × 6 right-angle socket | output bits `Q8..Q15` |
| `J5` | `QOUT_16-23` | 2 × 6 right-angle socket | output bits `Q16..Q23` |
| `J6` | `QOUT_24-31` | 2 × 6 right-angle socket | output bits `Q24..Q31` |
| `J7` | `TRIG_IN` | 2 × 6 right-angle socket | trigger inputs `TRIG_IN0..TRIG_IN7` |
| `J8` | QOUT sideband | 1 × 6 right-angle socket | output control/status breakout |
| `J9` | `EXT_CLK` | SMA | external clock input |
| `J10` | trigger control | 1 × 6 vertical socket | trigger control breakout |
| `J11` | trigger status | 1 × 6 vertical socket | trigger status/service breakout |
| `J12` | `AUX` | 2 × 6 right-angle socket | bidirectional auxiliary bus `AUX0..AUX7` |
| `J13` | buffered output | SMA | buffered `Q0` output |
| `J14` | buffered output | SMA | buffered `Q1` output |
| `J17` | trigger SMA | SMA | thresholded trigger input |
| `J18` | Qwiic-compatible I2C | JST-SH 1 × 4 | external I2C module connection |
| `J26` | `PPS_IN` | SMA | pulse-per-second input |

The QOUT, AUX, and trigger bus connectors use the same 2 × 6 mechanical style as a [Pmod-style expansion connector](https://digilent.com/reference/_media/reference/pmod/pmod-interface-specification-1_3_1.pdf), but the clock and trigger-control breakouts are simple headers rather than standard Pmod ports.

## QOUT And AUX

The four output connectors divide the 32-bit output bus into four 8-bit groups:

| Connector | Bits |
| --- | --- |
| `J3` | `Q0..Q7` |
| `J4` | `Q8..Q15` |
| `J5` | `Q16..Q23` |
| `J6` | `Q24..Q31` |

Signal grouping on the four 2 × 6 output connectors:

| Connector | Odd-row data pins | Even-row data pins |
| --- | --- | --- |
| `J3` | `Q0`, `Q1`, `Q2`, `Q3` | `Q4`, `Q5`, `Q6`, `Q7` |
| `J4` | `Q8`, `Q9`, `Q10`, `Q11` | `Q12`, `Q13`, `Q14`, `Q15` |
| `J5` | `Q16`, `Q17`, `Q18`, `Q19` | `Q20`, `Q21`, `Q22`, `Q23` |
| `J6` | `Q24`, `Q25`, `Q26`, `Q27` | `Q28`, `Q29`, `Q30`, `Q31` |

Each 2 × 6 connector also includes utility power and ground pins.

`J12` exports the auxiliary bus:

| Row | Signals |
| --- | --- |
| odd pins | `AUX3`, `AUX2`, `AUX1`, `AUX0`, then utility pins |
| even pins | `AUX7`, `AUX6`, `AUX5`, `AUX4`, then utility pins |

Each AUX bit defaults to input after reset and can be configured independently as an output through `pio_cfg`; output values are written through `pio_aux`. The [`ppaux`](ppaux.md) command samples pin levels only. Do not enable an AUX output while an external source is driving the same line.

QOUT sideband signals are presented on `J8`:

| Position | Signal |
| --- | --- |
| 1 | `STROBE` |
| 2 | `OE` |
| 3 | `STREAMER_CLK` |
| 4 | `QOUT_VALID` |
| 5 | `GND` |
| 6 | `+3.3V` |

`OE` is the physical output enable, `QOUT_VALID` is the `qout_valid` sample qualifier, and `STROBE` carries the `qout_strobe` sampling pulse.

Buffered SMA outputs:

* `J13` is tied to the buffered `Q0` path.
* `J14` is tied to the buffered `Q1` path.

The documentation intentionally uses "buffered SMA outputs" here. If you need to claim a specific source impedance or exact 50 Ω driver behavior, verify and document that explicitly from the circuit and measurement setup.
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

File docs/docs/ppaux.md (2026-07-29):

# ppaux

`ppaux` samples the AUX input port and prints formatted readings.

It is a simple observation/debugging tool for the 8-bit auxiliary input path.

The FPGA design exposes `AUX0..AUX7` as bidirectional pins with independent direction control, and all bits default to input after reset. `ppaux` is read-only: it reports the sampled pin levels but does not configure direction or drive output values. Those hardware controls are provided by `pio_cfg` and `pio_aux` for lower-level access.

## When to use it

Use `ppaux` when you want to:

* verify AUX wiring
* log slow-changing auxiliary states
* capture a quick digital trace without using the full readback path
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

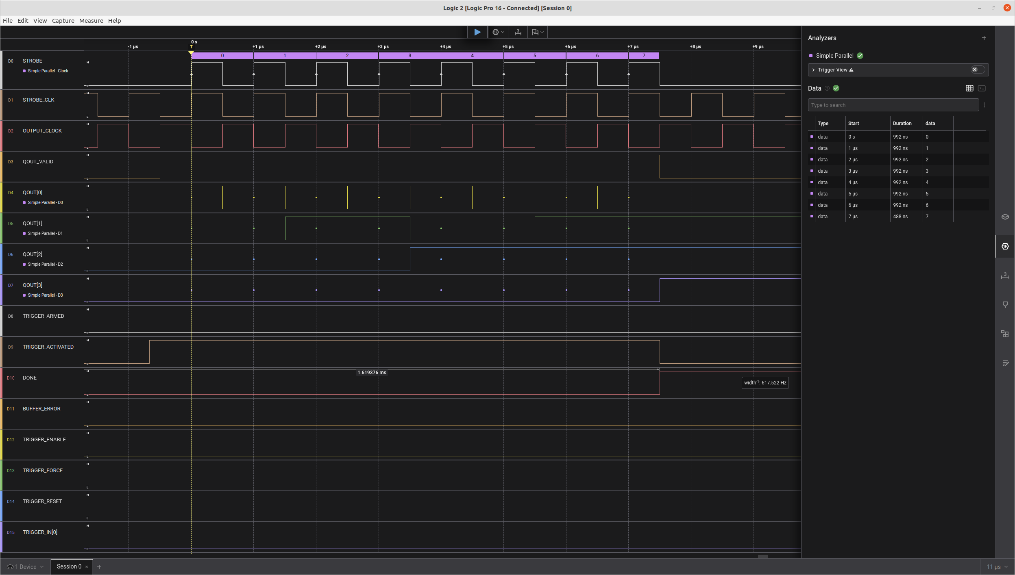
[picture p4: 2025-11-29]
docs/docs/img/seq1.png

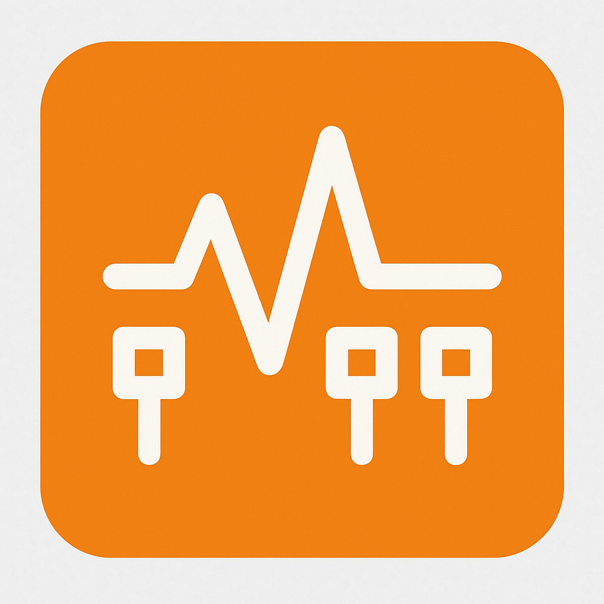
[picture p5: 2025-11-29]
docs/docs/img/pulsepins.jpg

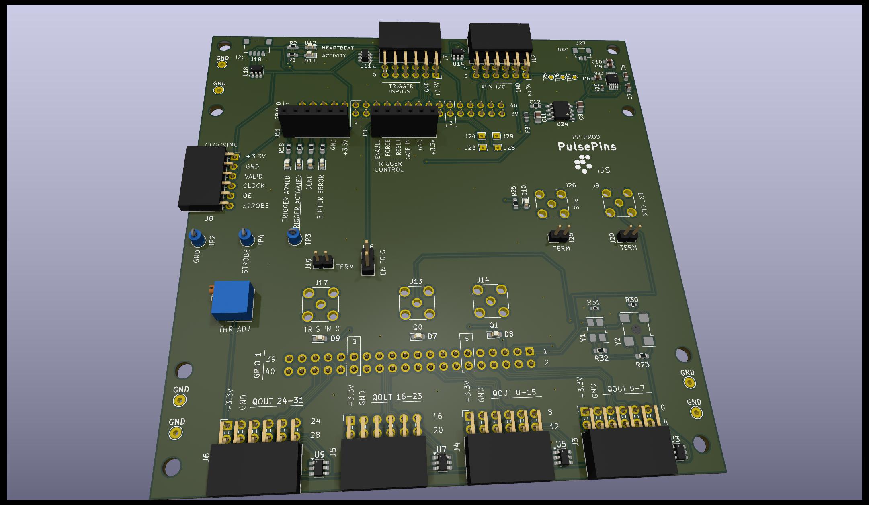
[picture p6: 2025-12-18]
pcb/ppshield_pmod/shield_render.jpg

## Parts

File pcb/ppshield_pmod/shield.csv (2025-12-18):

Reference | Qty | Value | DNP | Exclude from BOM | Exclude from Board | Footprint | Datasheet
C1,C3,C4,C5,C6,C9 | 6 | 100n |  |  |  | Capacitor_SMD:C_0603_1608Metric_Pad1.08x0.95mm_HandSolder | ~
C2,C10 | 2 | 1u |  |  |  | Capacitor_SMD:C_0603_1608Metric_Pad1.08x0.95mm_HandSolder | ~
C7 | 1 | 10n |  |  |  | Capacitor_SMD:C_0603_1608Metric_Pad1.08x0.95mm_HandSolder | ~
C8,C11 | 2 | 10uF |  |  |  | Capacitor_SMD:C_0805_2012Metric_Pad1.18x1.45mm_HandSolder | ~
C12 | 1 | 100n |  |  |  | Resistor_SMD:R_0603_1608Metric_Pad0.98x0.95mm_HandSolder | ~
D1,D2,D3,D4,D11,D12 | 6 | LED |  |  |  | LED_SMD:LED_0603_1608Metric_Pad1.05x0.95mm_HandSolder | ~
D5,D6 | 2 | BAV199DW |  |  |  | Package_TO_SOT_SMD:SOT-363_SC-70-6 | https://www.diodes.com/assets/Datasheets/ds30417.pdf
D7,D8,D9,D10 | 4 | D |  |  |  | LED_SMD:LED_0603_1608Metric_Pad1.05x0.95mm_HandSolder | ~
FB1 | 1 | MZ1608-601Y |  |  |  | Inductor_SMD:L_0603_1608Metric_Pad1.05x0.95mm_HandSolder | ~
IC1 | 1 | ADCMP604BKSZ-R2 |  |  |  | Package_TO_SOT_SMD:SOT-363_SC-70-6_Handsoldering | https://www.mouser.com/datasheet/2/609/ADCMP604_605-3120337.pdf
J1 | 1 | GPIO0 |  |  |  | Connector_PinSocket_2.54mm:PinSocket_2x20_P2.54mm_Vertical | ~
J2 | 1 | GPIO1 |  |  |  | Connector_PinSocket_2.54mm:PinSocket_2x20_P2.54mm_Vertical | ~
J3 | 1 | QOUT_0-7 |  |  |  | Connector_PinSocket_2.54mm:PinSocket_2x06_P2.54mm_Horizontal | ~
J4 | 1 | QOUT_8-15 |  |  |  | Connector_PinSocket_2.54mm:PinSocket_2x06_P2.54mm_Horizontal | ~
J5 | 1 | QOUT_16-23 |  |  |  | Connector_PinSocket_2.54mm:PinSocket_2x06_P2.54mm_Horizontal | ~
J6 | 1 | QOUT_24-31 |  |  |  | Connector_PinSocket_2.54mm:PinSocket_2x06_P2.54mm_Horizontal | ~
J7 | 1 | TRIG_IN |  |  |  | Connector_PinSocket_2.54mm:PinSocket_2x06_P2.54mm_Horizontal | ~
J8 | 1 | Conn_01x06 |  |  |  | Connector_PinSocket_2.54mm:PinSocket_1x06_P2.54mm_Horizontal | ~
J9,J13,J14,J17,J26 | 5 | Conn_Coaxial |  |  |  | Connector_Coaxial:SMA_Amphenol_132134-16_Vertical | ~
J10,J11 | 2 | Conn_01x06 |  |  |  | Connector_PinSocket_2.54mm:PinSocket_1x06_P2.54mm_Vertical | ~
J12 | 1 | Conn_02x06_Odd_Even |  |  |  | Connector_PinSocket_2.54mm:PinSocket_2x06_P2.54mm_Horizontal | ~
J16 | 1 | Conn_01x02_Pin |  |  |  | Connector_PinHeader_2.54mm:PinHeader_1x02_P2.54mm_Vertical | ~
J18 | 1 | Conn_01x04_Pin |  |  |  | Connector_JST:JST_SH_SM04B-SRSS-TB_1x04-1MP_P1.00mm_Horizontal | ~
J19,J20,J25 | 3 | Conn_01x02_Pin |  |  |  | Connector_PinHeader_2.00mm:PinHeader_1x02_P2.00mm_Vertical | ~
J23,J24,J28,J29 | 4 | Conn_01x01_Pin |  |  |  | TestPoint:TestPoint_THTPad_1.5x1.5mm_Drill0.7mm | ~
J27 | 1 | Conn_01x02_Socket |  |  |  | Connector_JST:JST_SH_BM02B-SRSS-TB_1x02-1MP_P1.00mm_Vertical | ~
R1,R2,R7,R8,R18,R19,R20,R21,R24,R25 | 10 | 330 |  |  |  | Resistor_SMD:R_0603_1608Metric_Pad0.98x0.95mm_HandSolder | ~
R4,R6,R17 | 3 | 50 |  |  |  | Resistor_SMD:R_0603_1608Metric_Pad0.98x0.95mm_HandSolder | ~
R5 | 1 | 100 |  |  |  | Resistor_SMD:R_0603_1608Metric_Pad0.98x0.95mm_HandSolder | ~
R22,R23,R32 | 3 | 10k |  |  |  | Resistor_SMD:R_0603_1608Metric_Pad0.98x0.95mm_HandSolder | ~
R26 | 1 | 0 |  |  |  | Capacitor_SMD:C_0402_1005Metric_Pad0.74x0.62mm_HandSolder | ~
R27,R28,R29,R30,R31 | 5 | 0 |  |  |  | Resistor_SMD:R_0402_1005Metric_Pad0.72x0.64mm_HandSolder | ~
RV1 | 1 | R_Potentiometer |  |  |  | Potentiometer_THT:Potentiometer_Bourns_3266P_Horizontal | ~
TP1,TP8,TP9,TP10,TP11,TP12 | 6 | TestPoint |  |  |  | TestPoint:TestPoint_THTPad_D2.0mm_Drill1.0mm | ~
TP2,TP3,TP4 | 3 | TestPoint |  |  |  | TestPoint:TestPoint_Loop_D1.80mm_Drill1.0mm_Beaded | ~
TP5,TP6,TP7 | 3 | TestPoint |  |  |  | TestPoint:TestPoint_Pad_D1.0mm | ~
U1 | 1 | 74LVC125 |  |  |  | Package_SO:SOIC-14_3.9x8.7mm_P1.27mm | http://www.ti.com/lit/gpn/sn74LVC125
U2,U3,U4,U5,U6,U7,U8,U9,U10,U11,U12,U13,U14,U18 | 14 | SRV05-4 |  |  |  | Package_TO_SOT_SMD:SOT-23-6 | http://www.onsemi.com/pub/Collateral/SRV05-4-D.PDF
U15,U16,U17,U19 | 4 | SN74LVC1G125DBV |  |  |  | Package_TO_SOT_SMD:SOT-23-5 | http://www.ti.com/lit/ds/symlink/sn74lvc1g125.pdf
U20,U21 | 2 | TPD1E05U06DYA |  |  |  | Diode_SMD:D_SOD-523 | https://www.ti.com/lit/ds/symlink/tpd1e05u06.pdf
U22 | 1 | MCP9808_MSOP |  |  |  | Package_SO:MSOP-8_3x3mm_P0.65mm | http://ww1.microchip.com/downloads/en/DeviceDoc/22203b.pdf
U23 | 1 | AD5693RxRM |  |  |  | Package_SO:MSOP-10_3x3mm_P0.5mm | https://www.analog.com/media/en/technical-documentation/data-sheets/AD5693R_5692R_5691R_5693.pdf
U24 | 1 | ADP7142ARDZ-3.3 |  |  |  | Package_SO:SOIC-8-1EP_3.9x4.9mm_P1.27mm_EP2.29x3mm | https://www.analog.com/media/en/technical-documentation/data-sheets/ADP7142.pdf
Y1 | 1 | SG-5032CBN |  |  |  | Crystal:Crystal_SMD_5032-4Pin_5.0x3.2mm
Y2 | 1 | SG-7050CAN |  |  |  | Oscillator:Oscillator_SMD_SeikoEpson_SG8002CA-4Pin_7.0x5.0mm | https://support.epson.biz/td/api/doc_check.php?dl=brief_SG7050CAN&lang=en

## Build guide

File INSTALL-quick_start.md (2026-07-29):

# PulsePins quick start

The canonical quick-start guide is part of the user manual:

* [Quick start](docs/docs/quick_start.md)

It covers downloading and flashing the released image, board access, changing the default password, baseline self-tests, a first finite output, and optional burn-in testing.

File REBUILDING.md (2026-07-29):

There are significant version-to-version differences in various tools used in the build process.
Here we document how to build the firmware and the software using a relatively new (as of 2026)
toolchain.

OS: Ubuntu 24.04 LTS, updated on 28 Mar 2026, kernel 6.17.0-19-generic

Submodules: PulsePins depends on the stand-alone asio library. After cloning the repository,
you can run: git submodule update --init

Firmware rebuild:
Run make in project root directory.

The ARM software needs to be compiled using a toolchain with compatible ABI. That is not easy to
do under Ubuntu 24.04, even using gcc cross-compilers (gcc-14-arm-linux-gnueabihf-base
g++-14-arm-linux-gnueabihf), due to glibc incompatibilities. The easiest approach is to set up
Ubuntu 20.04 in a container, as follows:

sudo apt update
sudo apt install -y software-properties-common
sudo add-apt-repository -y ppa:apptainer/ppa
sudo apt update
sudo apt install -y apptainer

mkdir -p ~/containers
cd ~/containers

apptainer build --sandbox ubuntu2004-gcc10 docker://ubuntu:20.04

Inside the container:

apt update
apt install -y g++
apt install -y \
  gcc-10-arm-linux-gnueabihf \
  g++-10-arm-linux-gnueabihf \
  binutils-arm-linux-gnueabihf \
  libc6-dev-armhf-cross \
  pkg-config \
  make \
  cmake \
  git

mkdir /work

Then run as:

apptainer shell --writable --fakeroot   --bind $HOME/$PULSEPINSROOT:/work   ubuntu2004-gcc10

cd $PULSEPINSROOT/c++
make

Release and ABI version updates:

Release labels use the YYYY.MM form, for example 2026.06. Update these files for a release-label-only change:

1. c++/ppversion.hh: VERSION is the release label printed by the C++ tools.
2. image/etc/issue: login/banner release label for the image tree.
3. docs/mkdocs.yml: extra.source_ref should point at the release tag/ref used by documentation source links.

Do not hand-edit generated or historical CLI transcripts just to change the displayed version string, such
as recipes/ppqout or tests/README.xtal_on_DE10_Nano. Regenerate those examples only when their output is
being intentionally refreshed.

The FPGA/HPS software ABI version is separate from the release label. Bump it only when the HPS software and
bitstream must reject older incompatible counterparts, for example after a register map or protocol change.
Keep these values in sync:

1. c++/ppversion.hh: const int version.
2. base_hps.qsys: the sysid_qsys_1 id parameter.
3. c++/artifacts/hps_0.h: SYSID_QSYS_1_ID for development-machine builds using USE_PREGENERATED=1.

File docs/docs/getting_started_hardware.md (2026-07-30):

# Hardware setup

Use this page for board access, signal-level context, and optional hardware after following the [Quick start](quick_start.md). Build and deployment workflows for repository changes are documented separately under [Build and deployment](build.md).

## Released baseline

The default supported setup is intentionally small:

* one [DE10-Nano](https://www.terasic.com.tw/cgi-bin/page/archive.pl?Language=English&CategoryNo=167&No=1046)
* the latest released PulsePins SD-card image
* no shield or external loopback wiring for baseline validation

Use the Terasic board documentation for power, physical header pins, UART driver setup, switches, and board-level electrical limits. The [DE10-Nano signal reference](de10_nano_reference.md) documents the PulsePins assignments within the FPGA design.

## Network access

The released image requests an Ethernet address using DHCP. Its default MAC address is `D6:7D:AE:B3:0E:BA`; use that value to identify the board in the router's DHCP lease list.

Connect with:

```bash
ssh root@BOARD_IP
```

The initial password is `eit`. Change it with `passwd` before using the board on an untrusted network. For passwordless access, run `ssh-copy-id root@BOARD_IP` from the development machine.

## UART fallback

The USB mini connector marked `UART` provides a serial console when Ethernet configuration or address discovery is not working. Connect it to a host, open the serial device using the settings documented by Terasic for the DE10-Nano, and log in with the same released-image credentials.

Use the serial console to inspect or change network configuration before retrying SSH.

## Output and input signals

PulsePins uses 3.3 V LVTTL signaling. Check voltage compatibility and establish a common ground before connecting laboratory equipment or another digital device.

Useful references:

* [DE10-Nano signal reference](de10_nano_reference.md) for base-board assignments, output enable, LEDs, and manual trigger controls
* [PP_PMOD hardware reference](pp_pmod_reference.md) for connector-level details on the optional reference shield
* [Sequencer model](sequencer_model.md#output-enable-and-readback) for high-impedance input/readback behavior
* [Readback](readback.md#readback-of-external-signals) for external signal capture

## Baseline validation

Before running the board tests, disconnect external circuits from driven PulsePins signals or verify that they can safely accept generated 3.3 V patterns. The tests enable outputs and exercise nonzero values.

Run `run_all_tests` before diagnosing optional hardware or developing a larger experiment. A clean run prints `SUCCESS`; see [Quick start](quick_start.md#4-validate-the-baseline-image) for the first-board procedure and [Testing procedures](testing.md) for test levels, logs, and troubleshooting.

For a first externally observed signal, follow [First finite output](manual/first_output.md), then continue with the [User manual](examples.md).

## Optional PP_PMOD profile

`PP_PMOD` is a published KiCad reference shield, not a required baseline or prebuilt accessory. It breaks out the output, trigger, AUX, clock, PPS, I2C, and status signals and can be used directly or adapted into a custom interface board.

Digital trigger routing can be checked with `pptrig`, but the thresholded SMA comparator path should not be treated as systematically validated for every assembly and signal source. Record its threshold, termination, source, and observed waveform when testing it.

Start with:

* [ppboards shield overview](ppboards.md)
* [PP_PMOD overview](pp_pmod.md)
* [PP_PMOD hardware reference](pp_pmod_reference.md)

Record the exact shield revision, populated options, jumper positions, cabling, and external equipment whenever reporting a hardware result.

## Working from a repository build

For hardware-backed development rather than released-image setup:

* use [Build and deployment](build.md#recommended-workflows) for `make`, `make copy_all`, and the required FPGA reload
* use [Testing procedures](testing.md) to choose between `make dev-check`, `make board-smoke`, and `run_all_tests`
* use the [Contributor overview](hacking.md) for subsystem-specific starting points

When validating a change, record the board revision, image and software versions, clock source, wiring, exact commands, expected result, and observed result.

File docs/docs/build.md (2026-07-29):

## Build and deployment

PulsePins is built as a combined FPGA hardware, ARM software, and optional image-assembly project.

The main build entry point is the repository root [`Makefile`]({{ source_file("Makefile") }}).

### Top-level build flow

Running `make` at the repository root performs these steps:

1. Generate `base_hps.sopcinfo` from [`base_hps.qsys`]({{ source_file("base_hps.qsys") }})
2. Generate the top-level HPS header `hps_0.h` for compilation; the checked-in pregenerated copy is [`c++/artifacts/hps_0.h`]({{ source_file("c++/artifacts/hps_0.h") }})
3. Compile the [Quartus Prime](https://www.altera.com/products/development-tools/quartus) project into `pulsepins.sof`
4. Run the Quartus timing/report checker
5. Convert the SOF bitstream into `pulsepins.rbf`
6. Build the ARM C++ programs in [`c++/`]({{ source_file("c++/") }})

Relevant targets in [`Makefile`]({{ source_file("Makefile") }}):

* `all` - full hardware + C++ build
* `dev-check` - consolidated local checks
* `timing-check` - parse existing Quartus reports and enforce timing signoff checks
* `timing-sdc-check` - parse existing Quartus reports and check only project SDC handling
* `board-smoke` - fast manual live-board smoke pass against local build outputs
* `copy` - copy `pulsepins.rbf` to the target board
* `copy_boot` - copy the RBF to the boot partition path
* `copy_all` - copy hardware, C++, Python, tests, and I2C helpers to the target board
* `copy_all_img` / `copy_all_image` - stage the same content into the image tree
* `lint` - run Verible lint on top-level SystemVerilog/Verilog RTL
* `clean` - remove generated build outputs across subprojects

For a quick manual live-board regression pass after the build outputs already exist, use `make board-smoke`. That target wraps [`scripts/board_smoke.sh`]({{ source_file("scripts/board_smoke.sh") }}), redeploys the local `pulsepins.rbf` bitstream and `pptool`, `ppscpi`, and `ppwebgui` binaries, reloads the FPGA, and runs a small finite smoke sequence against the board plus the two network services, including a few selected failure-path checks (`ppscpi` error queue, `ppwebgui` HTTP `400`, and `ppwebgui` HTTP `504`). It does not rebuild those build outputs first. Override the target board with `TARGETHOST=...` when needed.

For the normal local contributor checks, use:

```bash
make dev-check
```

That target runs C++, documentation, and Python checks without running the FPGA build or accessing a live board.

### FPGA hardware build

The FPGA build depends on:

* top-level project files at the repository root
* generated Platform Designer/Qsys outputs
* IP sources under [`ip/`]({{ source_file("ip/") }})
* `*_hw.tcl` integration files used by the Quartus system description

Platform Designer/Qsys is Intel/Altera's system-integration tool for assembling FPGA IP blocks, interconnects, clocks, resets, and HPS-to-FPGA interfaces into the generated hardware system.

Important outputs:

* `base_hps.sopcinfo` - system description generated from [`base_hps.qsys`]({{ source_file("base_hps.qsys") }})
* top-level generated `hps_0.h` - HPS/FPGA address map header consumed by normal hardware/C++ builds; the checked-in pregenerated copy is [`c++/artifacts/hps_0.h`]({{ source_file("c++/artifacts/hps_0.h") }})
* `pulsepins.sof` - SRAM Object File; Quartus-generated volatile FPGA programming image used for direct FPGA programming/debug loading
* `pulsepins.rbf` - Raw Binary File; compact FPGA configuration bitstream used for boot/runtime deployment, including `FPGA-writeConfig` and boot-partition workflows

`QDIR` can be overridden to point to a local Quartus `bin` directory, and `Makefile.local` can provide local overrides without changing the tracked build file. Qsys tools are resolved from the sibling `sopc_builder/bin` directory through `QUARTUS_ROOT` and `QSYS_DIR`, so the FPGA build does not rely on global `PATH` for Quartus tools. The top-level FPGA build runs [`scripts/check_quartus_timing.py`]({{ source_file("scripts/check_quartus_timing.py") }}) after Quartus compilation by default. Use `make CHECK_QUARTUS_TIMING=0` only for local/debug builds where timing signoff should be skipped deliberately.

Clocking is a central part of the hardware build. The hardware design uses PLL-generated `core_clk` and `int_clk`, a
selectable `streamer_clk` path, and explicit top-level timing constraints in [`pulsepins.sdc`]({{ source_file("pulsepins.sdc") }}). For the detailed clocking
model and software clock control, see `clock_domain.md`.

After a Quartus build, run `make timing-check` from the repository root to re-check existing reports without rebuilding. The checker parses the Quartus reports and fails on ignored project SDC constraints, missing streamer generated clocks, PLL clock cross-check warnings, unconstrained paths, or negative timing slack. Use `make timing-sdc-check` for the narrower project-SDC-only check.

### C++ build

The ARM software lives in [`c++/`]({{ source_file("c++/") }}).

Key targets in [`c++/Makefile`]({{ source_file("c++/Makefile") }}):

* `build` - build `pptool`, `ppscpi`, `ppwebgui`, `pllcalc`, and `unit_tests`
* `copy` - copy the executables to the target board and create the usual symlinks to `pptool`
* `copy_sources` - copy source files for target-board rebuilds
* `copy_img` / `copy_sources_img` - stage executables or sources into the image tree

The build expects:

* top-level generated `hps_0.h` from the hardware build; builds on a development machine use the checked-in pregenerated [`c++/artifacts/hps_0.h`]({{ source_file("c++/artifacts/hps_0.h") }}) with `USE_PREGENERATED=1`
* SoC EDS / hwlib headers
* the Lua sources vendored under [`c++/third_party/lua`]({{ source_file("c++/third_party/lua/") }})

The DMA-backed streamer uses the FPGA design's Intel/Altera Modular Scatter-Gather DMA block through the HPS-side [`streamer_dma.hh`]({{ source_file("c++/streamer_dma.hh") }}) wrapper, so DMA support depends on both the generated hardware address map and the SoC EDS / hwlib-facing build environment.

By default the build is cross-compiling for ARM, but the sources are also structured so they can be copied to the board and built there.

`ppwebgui` and `pllcalc` are standalone executables like `ppscpi`, not `pptool` symlink modes. They are included in the normal `build` and `copy` targets.

The C++ side also participates in clock configuration. The `FPGA` wrapper and PLL helper classes can reconfigure the
internal PLLs and switch the active streamer clock source, so clocking should be thought of as a hardware/software
boundary rather than a purely RTL concern.

The C++ ownership split is deliberate:

* [`c++/startup.hh`]({{ source_file("c++/startup.hh") }}) applies the common startup behavior
* [`c++/options.hh`]({{ source_file("c++/options.hh") }}) resolves CLI/environment clocking choices into typed policy objects
* [`c++/fpga.hh`]({{ source_file("c++/fpga.hh") }}) owns top-level source switching and shared hardware state
* [`c++/pll_clk.hh`]({{ source_file("c++/pll_clk.hh") }}) owns PLL reconfiguration wrappers

### Python bindings

The Python bindings live in [`python/`]({{ source_file("python/") }}) and are built with CMake and nanobind. A board-native build needs both `pytest` and `nanobind` installed in the active Python environment.

Production Python builds are expected to happen on the DE10-Nano board itself.
Development-machine builds are useful for syntax/import/API testing, but true Python cross-
compilation is not supported.

The [`python/Makefile`]({{ source_file("python/Makefile") }}) provides:

* `build` - configure and build the extension modules under `python/build`
* `test` - run the full Python test suite, including board-backed tests
* `test-host` - run only the Python tests that do not require a board (`-m "not hardware"`)
* `copy_sources` / `copy_misc` - copy sources to the target board
* `copy_sources_img` - stage the sources into the image tree

The CMake configuration builds two modules:

* `pp`
* `pp_impl`

The `pp` module is split across multiple translation units: [`python/pp.cc`]({{ source_file("python/pp.cc") }}) contains the nanobind module entry point, while the actual bindings live in [`python/pp_bind_*.cc`]({{ source_file("python/") }}).

### IP-level simulation/testbenches

[`ip/Makefile`]({{ source_file("ip/Makefile") }}) delegates to IP subdirectories and is mainly used for RTL testbenches.

Running `make -C ip test` executes the integrated per-IP test targets for directories such as:

* `combiner`
* `combiner_comb`
* `combiner_trig`
* `counter`
* `rl_encoder_if`
* `st_mux`
* `streamer`
* `ts_core`

### Image assembly

The `image/` directory stages files into an SD-card image tree for the DE10-Nano.

The top-level `copy_all_img` target populates `image/ext/home/root/` with:

* the FPGA RBF image
* C++ executables and source trees
* Python sources
* tests
* I2C helpers

The image workflow expects an external base image and additional binary assets that are not stored in this repository.

Use `IMAGE_ROOT=/path/to/image make copy_all_img` to stage into a different image tree. `IMGROOT` remains the home-root staging path and defaults to `$(IMAGE_ROOT)/ext/home/root`.

### Recommended workflows

Hardware + software build:

```bash
make
```

Copy the complete board bundle to the target board:

```bash
make copy_all
```

`make copy_all` copies the new bitstream and software but does not program the FPGA. From the root home directory on the board, load the copied bitstream before testing the updated software:

```bash
FPGA-writeConfig -f pulsepins.rbf
```

Treat this reload as required after `make copy_all`; otherwise the new executables may run against a stale or ABI-incompatible FPGA image. Then run the appropriate checks from [Testing procedures](testing.md).

Deployment targets use `TARGETHOST` as the board host name and `SCP_TARGET` as the exact ssh/scp destination. By default `SCP_TARGET=$(TARGETHOST)`; override `SCP_TARGET=user@host` when the copy user or ssh destination differs from the board host name.

This also installs the Bash-completion file for the `pptool` command family onto the live board under `/etc/profile.d/pulsepins-completion.sh`.

Install Bash completion for the `pptool` command family on the live board:

```bash
sudo ./scripts/install_bash_completion.sh
```

The prepackaged quick-start SD-card images already ship with this completion installed, so the installer is only needed for manually provisioned systems.

If you stage a board image through the repository Makefiles, `make copy_all_img` (or `make copy_all_image`) also stages the same completion file into `image/ext/etc/profile.d/pulsepins-completion.sh`.

Build only the Python bindings:

```bash
make -C python USE_PREGENERATED=1 build
```

`USE_PREGENERATED=1` selects the checked-in pregenerated [`c++/artifacts/hps_0.h`]({{ source_file("c++/artifacts/hps_0.h") }}) instead of the top-level generated header; use it when the generated header is unavailable.

Run RTL testbenches:

```bash
make -C ip test
```

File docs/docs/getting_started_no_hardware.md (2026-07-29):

# Development-machine work without hardware

PulsePins is primarily a hardware-backed project, but useful contribution work is possible without owning a board.

## Suitable contribution areas

* documentation in [`docs/`]({{ source_file("docs/") }}) and top-level [`README.md`]({{ source_file("README.md") }}) files
* Python bindings in [`python/`]({{ source_file("python/") }})
* C++ sequence handling and command-line behavior in [`c++/`]({{ source_file("c++/") }})
* RTL simulation and testbenches in [`ip/`]({{ source_file("ip/") }})

## Useful commands

Build the documentation site:

```bash
make -C docs site
```

Build and test the Python bindings on a development machine:

```bash
make -C python USE_PREGENERATED=1 build test-host
```

This local build uses the checked-in pregenerated HPS header from [`c++/artifacts/`]({{ source_file("c++/artifacts/") }}) and intentionally skips tests marked as hardware-only. It is useful for syntax/import/API validation, but it is not a supported
replacement for building the production Python modules natively on the DE10-Nano. True Python
cross-compilation is not supported.

Run RTL testbenches:

```bash
make -C ip test
```

## Good first contributions

* improve docs clarity
* add recipes and examples
* improve parser validation
* add simulation tests
* improve contributor onboarding

## Areas to treat carefully

Without hardware, avoid making strong claims about:

* timing accuracy
* active clocking behavior on the board
* exact runtime behavior of deployment scripts on the target-board image
* measured outputs from `ppfreq`, `ppts`, `pptemp`, and related tools

For those cases, document assumptions and leave room for later hardware verification.

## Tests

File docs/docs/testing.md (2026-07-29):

# Testing procedures

PulsePins was designed from the start to support a high degree of internal self-testing. For this
reason, the FPGA fabric includes a run-length encoder for reading back the generated stream and
comparing it against expected results. These tests are performed with the [pptest](pptest.md)
tool. A collection of shell scripts can be found in the [`tests/`]({{ source_file("tests/") }}) subdirectory. To start one sweep
of the test battery, run [`run_all_tests`]({{ source_file("tests/run_all_tests") }}). If any error is encountered, testing stops immediately.
Successful completion is reported by printing the message ``SUCCESS``.

The hardware tests enable output drivers and exercise nonzero 3.3 V patterns. Disconnect external circuits from driven PulsePins signals, or verify that they can safely accept those patterns, before starting a sweep.

One can run the tests continuously using [`run_all_tests_forever`]({{ source_file("tests/run_all_tests_forever") }}) to perform intensive
stress testing. Current-source builds collect logs under `/var/volatile/pulsepins-test-logs` for inspection:
`report` records the `pptest` version, bitstream timestamp, and successful-run timestamps, while
`report.run_N` files contain per-run output. Pass `-no-report-files` to avoid writing the
accumulating `report.run_N` files during long burn-in runs. The runner exits with failure on the
first failed sweep, including child processes killed by signals.

## Wiring up for testing

Recommended color coding for connecting the DE10-Nano to a Saleae logic analyzer is provided in
the comments in the [`pulsepins.sv`]({{ source_file("pulsepins.sv") }}) design file.

The image below shows a testing jig. It uses custom cables to connect the logic
analyzer to both GPIO ports. Eight bits of qout on the Arduino port are connected to LEDs.
An oscilloscope is connected to clock signals on the Arduino port. Some wires for hooking up
external clock sources are also visible.

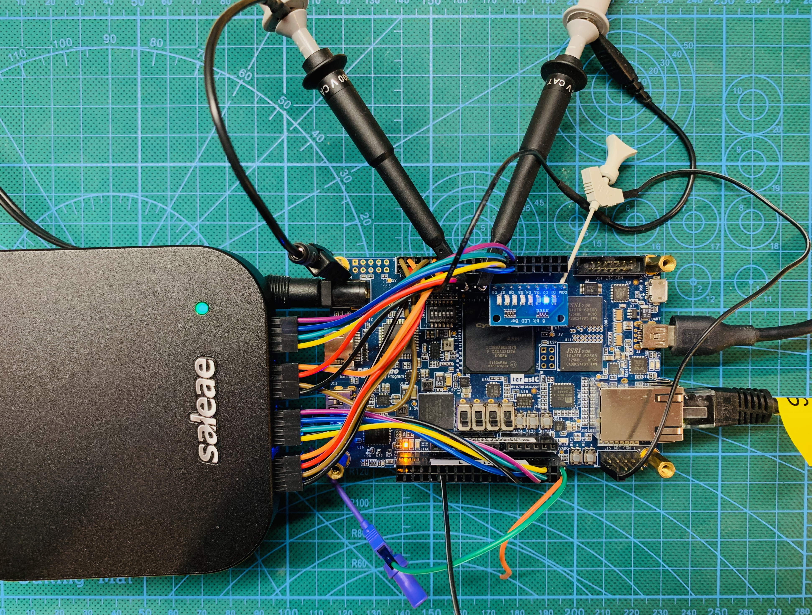
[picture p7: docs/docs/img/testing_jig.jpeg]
PulsePins testing jig


## Arduino header

Selected output and clock signals are brought out on the Arduino header for probing and tests. See the [DE10-Nano signal reference](de10_nano_reference.md#arduino-header) for the current mapping.

## Manual testing

Some test procedures require additional external test equipment or external wiring.

### Manual board smoke

For a quick hand-run live-board regression check from the repository root, use:

```bash
make board-smoke
```

This is intentionally smaller and faster than [`run_all_tests`]({{ source_file("tests/run_all_tests") }}): it redeploys the locally built FPGA image and board executables, reloads the FPGA, runs a few finite `pptool` checks, and exercises both `ppscpi` and `ppwebgui` over the network. Override the target board with `TARGETHOST=...` if needed.

Before touching the board, run the local checks:

```bash
make dev-check
```

Use the three levels like this:

* `make dev-check` - local build and test checks
* `make board-smoke` - fast manual live-board regression test
* [`run_all_tests`]({{ source_file("tests/run_all_tests") }}) - intensive target-board validation sweep

### Random number generator

The built-in random number generator can be tested by running ``pptest 19``. By connecting
an output signal to a spectrum analyzer, one can examine the whiteness of the spectrum.
When Q0 or Q1 is suitable, use the buffered SMA outputs on the [PP_PMOD board](ppboards.md);
use appropriate external buffering or probing for other outputs.

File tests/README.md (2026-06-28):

A comprehensive collection of tests covering most of the implemented functionality of PulsePins, along with some documentation for testing procedures.

* run_all_tests: runs (almost) all tests from the collection once
* run_all_tests_forever: repeatedly runs all tests for burn-in testing (logs are written under `/var/volatile/pulsepins-test-logs`; `report` contains the `pptest` version and bitstream timestamp headers plus successful-run timestamps; pass `-no-report-files` to skip the accumulating `report.run_N` files)
* command recipe files now live in `../recipes/`
* sequence fixture files such as `sequence.simple`, `sequence.simple.ppbin`, and `vcd.simple1` are copied together with the executable tests and are used by the `ppplay` playback checks

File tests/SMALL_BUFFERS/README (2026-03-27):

Set of tests for reduced buffer sizes (`SMALL_BUFFERS` in `ip/streamer/config.vh`).

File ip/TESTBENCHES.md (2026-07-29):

# IP testbenches

This file provides an overview of the simulation testbench tree under `ip/`.

## What these testbenches are for

The testbenches in `ip/` mix several styles of verification:

* direct functional checks of datapath behavior
* Avalon-MM / Avalon-ST wrapper and register-interface checks
* integration tests across multiple internal blocks
* randomized regression loops for repeated register-programmed scenarios
* timing/latency-sensitive checks where cycle alignment matters

The goal is not only to catch regressions, but also to explain what each subsystem promises at its external interface.

## Common conventions

Most testbenches follow these conventions:

* generate a simple local simulation clock and short reset pulse
* print `SUCCESS` and create a `SUCCESS` marker file on pass
* write a `.ucdb` coverage file with a subsystem-specific name
* use `$strobe` on selected DUT internals so failures can be diagnosed without immediately opening a waveform viewer

The comments added to each testbench focus on purpose and scope rather than on every signal assignment.

## How to read the tree

### Streamer family

The streamer tree is the core of PulsePins and is split by verification layer:

* `streamer/tb_streamer/` - top-level streamer datapath and feature integration
* `streamer/tb_st_interface/` - Avalon-ST / Avalon-MM wrapper behavior
* `streamer/tb_input_fifo/` - ingress FIFO behavior and backpressure
* `streamer/tb_preprocessor/` - store/replay preprocessor logic in isolation
* `streamer/tb_input_fifo+preprocessor/` - combined ingress + preprocessor path
* `streamer/tb_chain_trigger/` - multi-stage trigger-program engine
* `streamer/tb_and_trigger/` - simpler trigger primitive

### Readback

* `rl_encoder_if/tb_rl_encoder/` - core run-length encoder behavior
* `rl_encoder_if/tb_rl_encoder_if/` - software-visible wrapper/interface behavior

### Counter subsystem

Each `counter/tb_*` directory targets one measurement primitive or the top-level counter wrapper.

### Other IPs

* `combiner*` - qout and trigger combiner datapaths and wrappers
* `st_mux/` - Avalon-ST multiplexer behavior
* `ts_core/` - timestamp capture core
* `freq_meter/` - frequency meter
* `misc/` - small reusable support blocks

## Suggested reading order

For the main PulsePins data path, start with:

1. `streamer/tb_streamer/`
2. `streamer/tb_st_interface/`
3. `streamer/tb_input_fifo+preprocessor/`
4. `streamer/tb_chain_trigger/`
5. `rl_encoder_if/tb_rl_encoder_if/`
6. `counter/tb_counter_if/`

That sequence follows a software-generated sequence through the streamer and then through the readback and counter paths.

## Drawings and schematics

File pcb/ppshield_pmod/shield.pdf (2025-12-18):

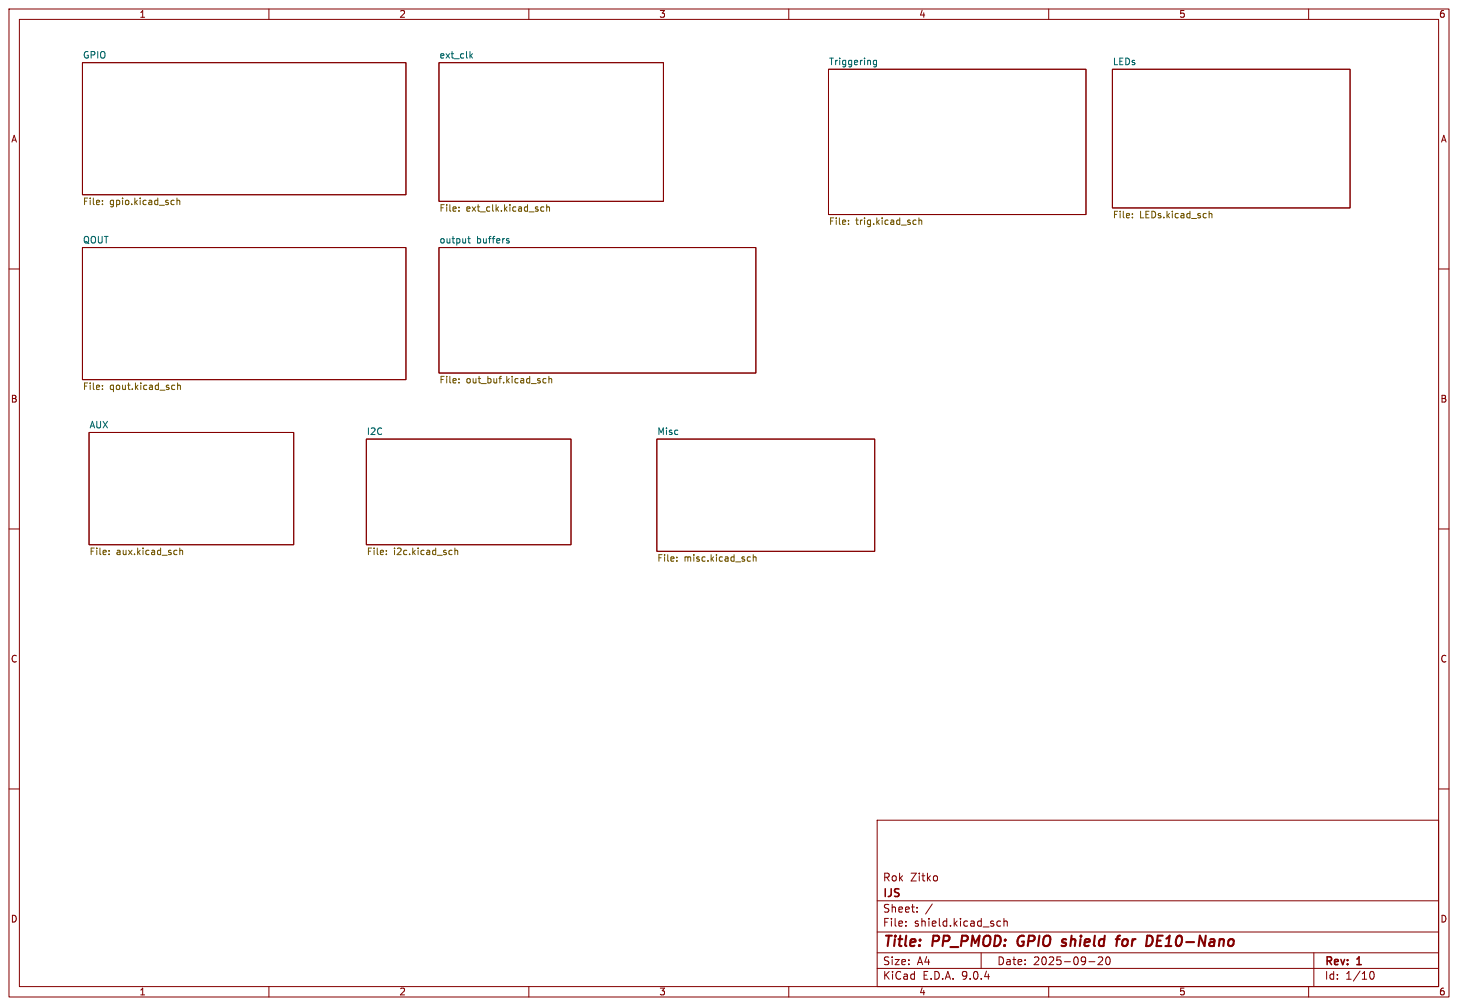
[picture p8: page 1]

LEDs File: LEDs.kicad_sch Triggering File: trig.kicad_sch Misc File: misc.kicad_sch

File: shield.kicad_sch Sheet: /
Id: 1/10 Title: PP_PMOD: GPIO shield for DE10-Nano

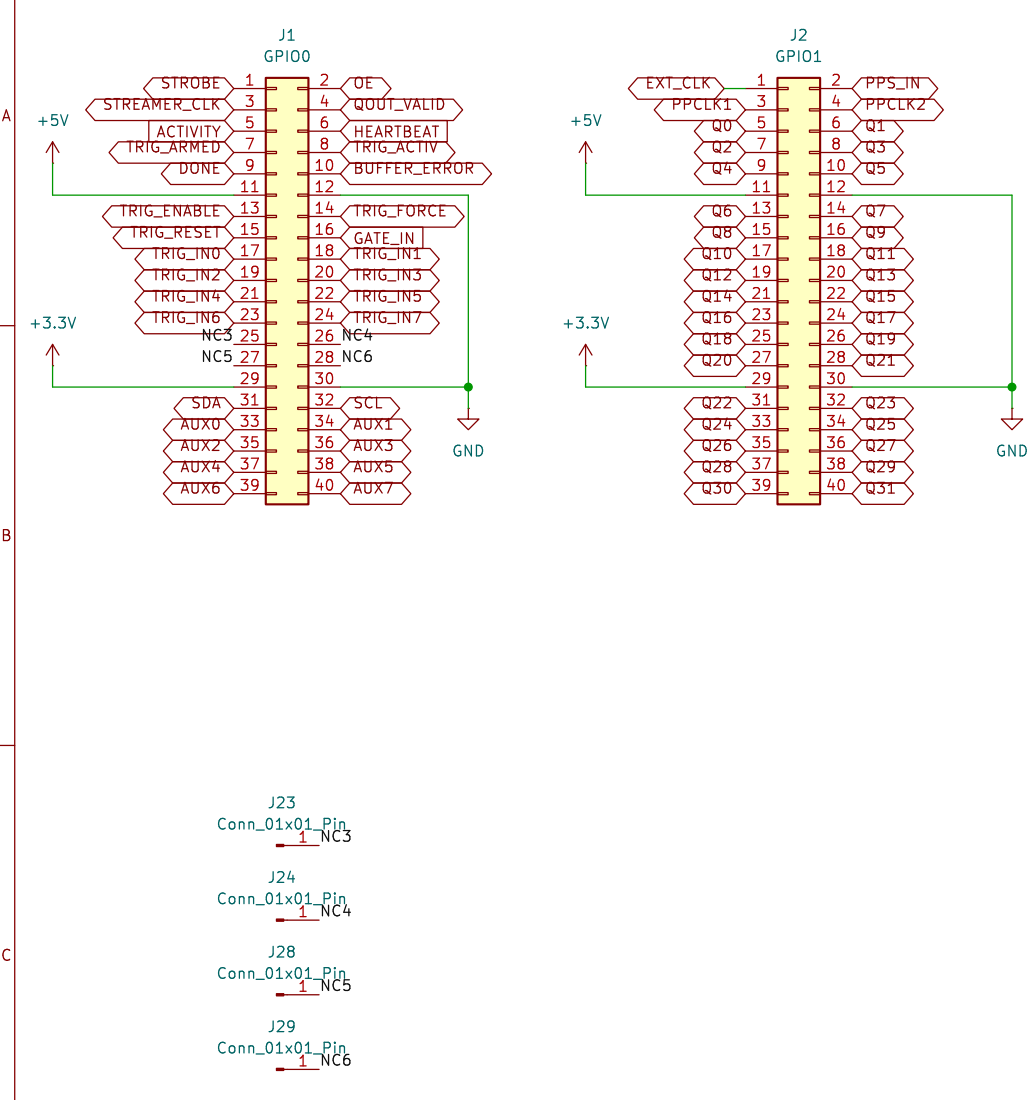
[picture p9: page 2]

File: gpio.kicad_sch Sheet: /GPIO/
Id: 2/10 Title: PP_PMOD: GPIO shield for DE10-Nano

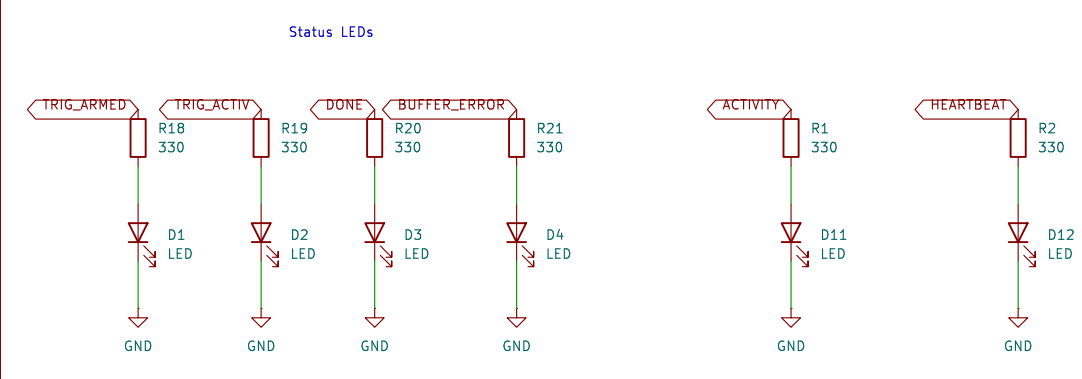
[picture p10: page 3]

File: LEDs.kicad_sch Sheet: /LEDs/
Id: 3/10 Title: PP_PMOD: GPIO shield for DE10-Nano

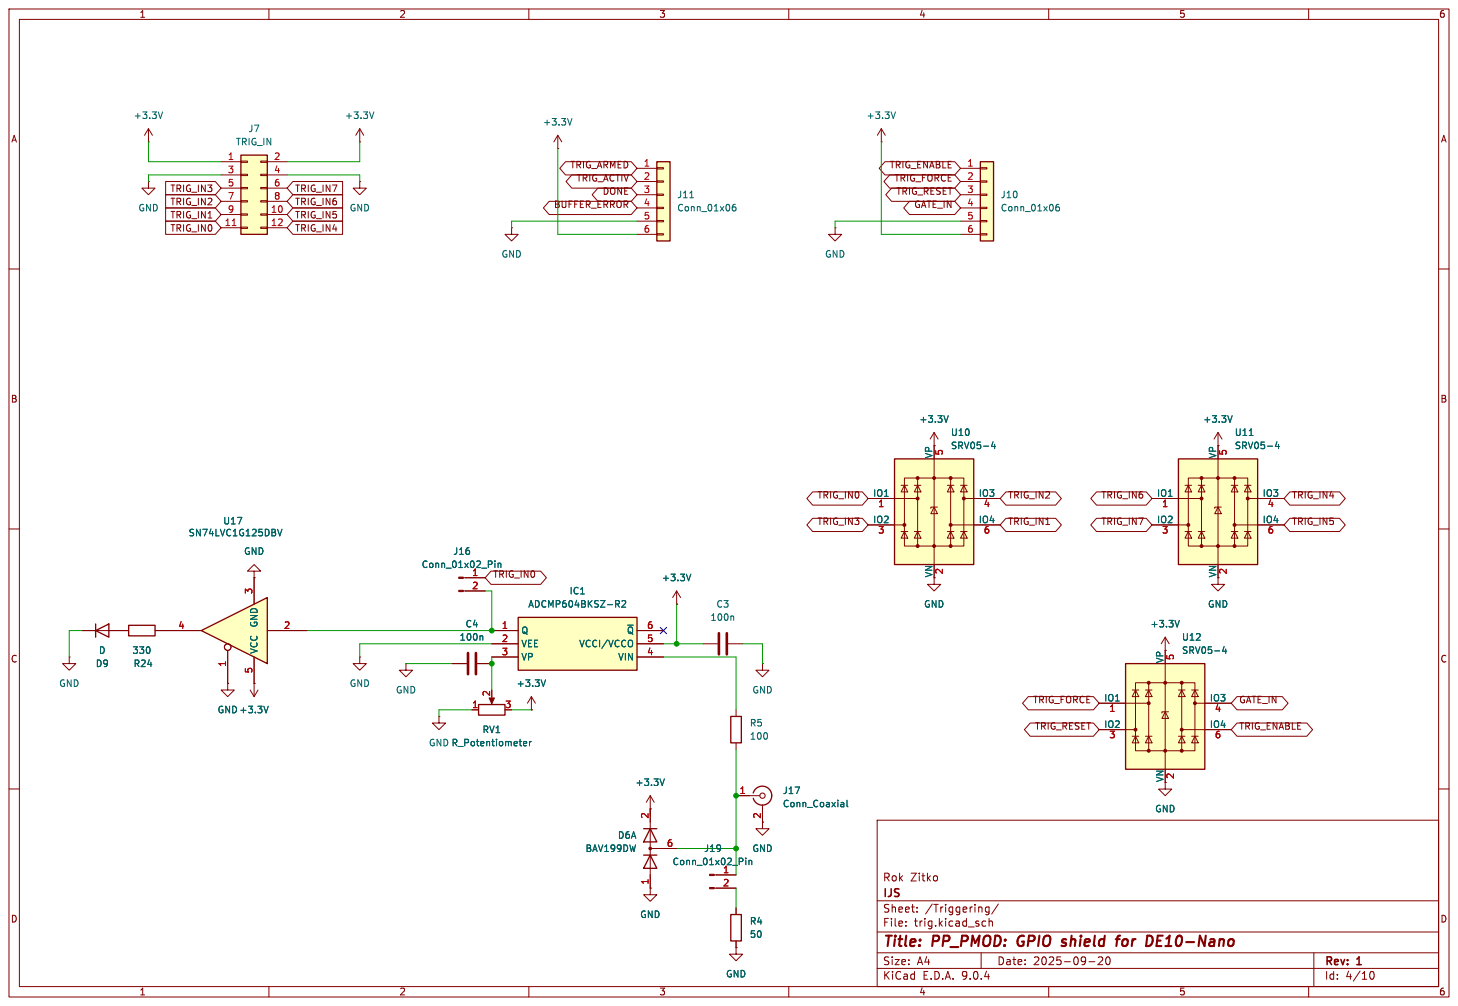
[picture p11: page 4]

File: trig.kicad_sch Sheet: /Triggering/
Id: 4/10 Title: PP_PMOD: GPIO shield for DE10-Nano

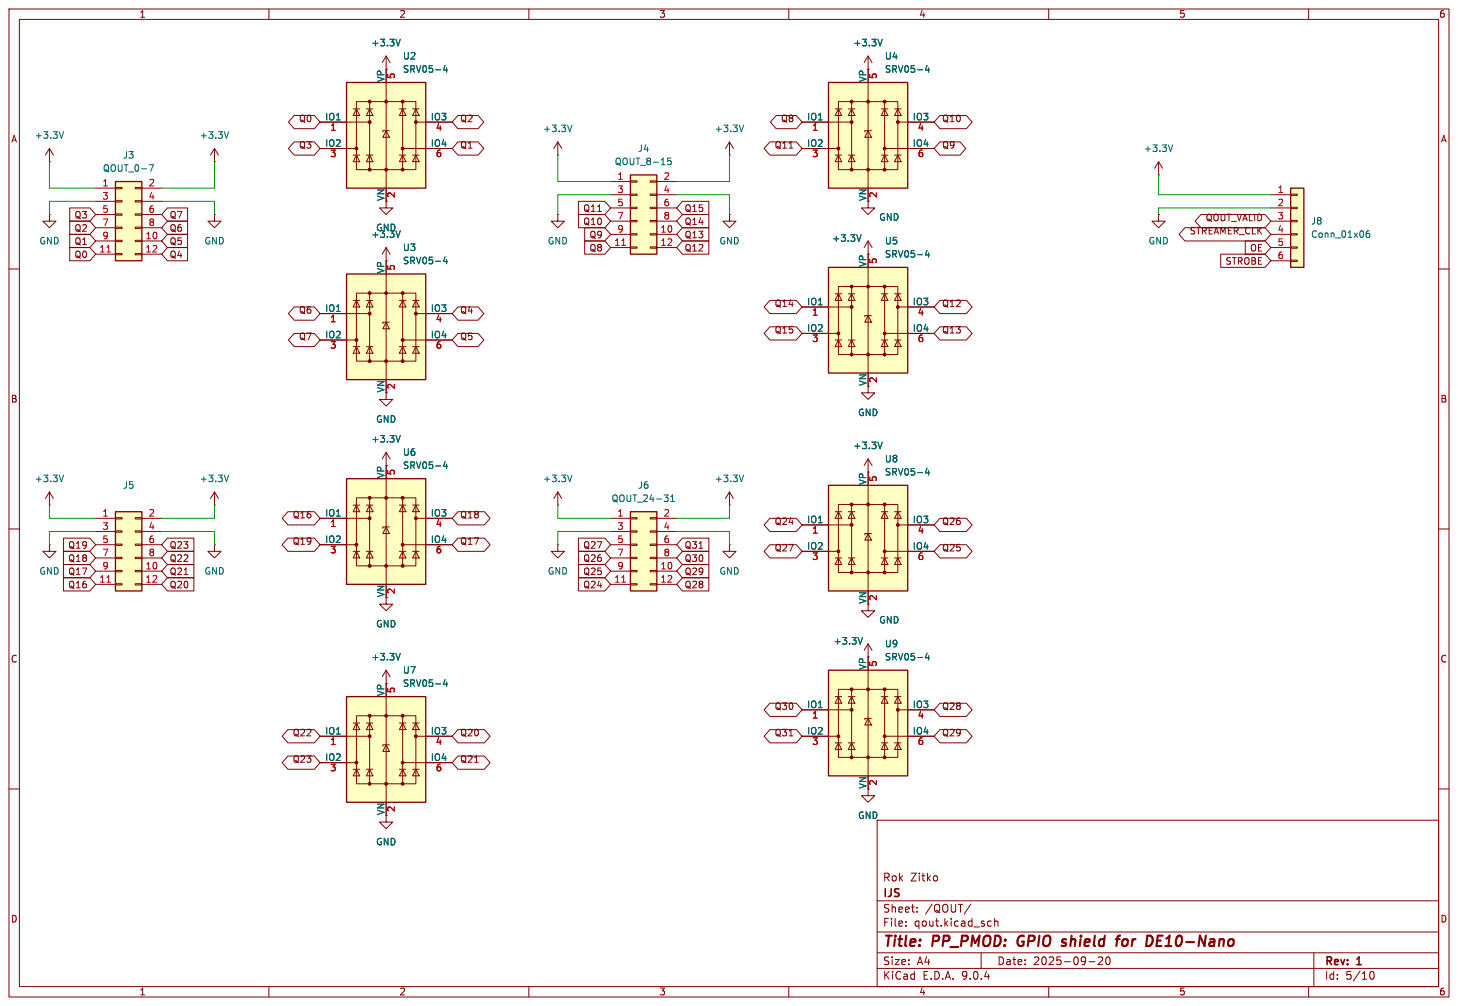
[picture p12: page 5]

File: qout.kicad_sch Sheet: /QOUT/
Id: 5/10 Title: PP_PMOD: GPIO shield for DE10-Nano

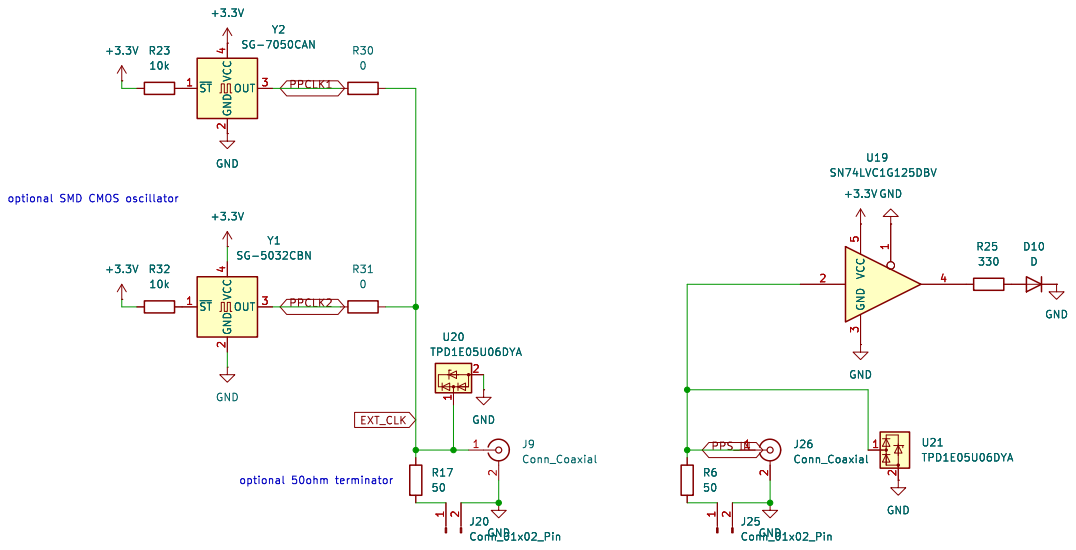
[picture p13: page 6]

File: ext_clk.kicad_sch Sheet: /ext_clk/
Id: 6/10 Title: PP_PMOD: GPIO shield for DE10-Nano

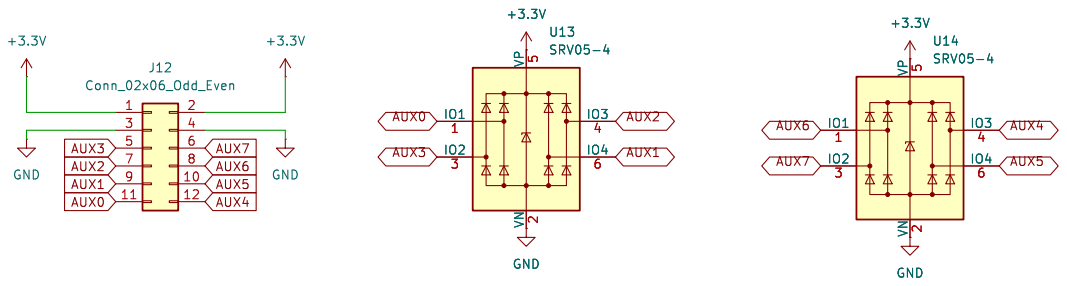
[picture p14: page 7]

File: aux.kicad_sch Sheet: /AUX/
Id: 7/10 Title: PP_PMOD: GPIO shield for DE10-Nano

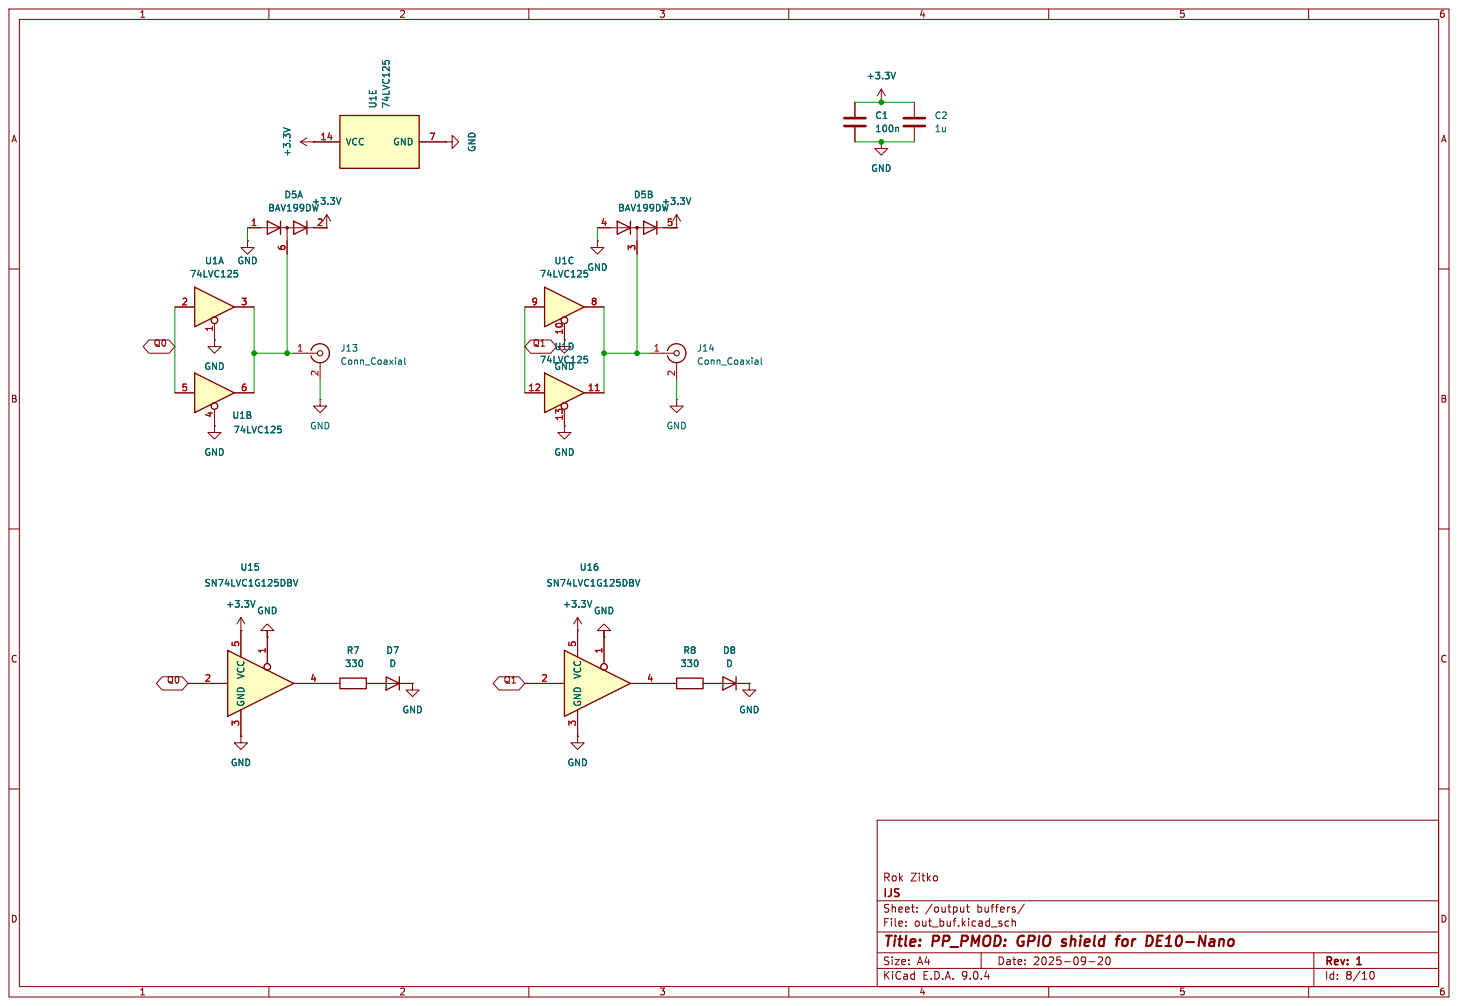
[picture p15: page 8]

IJS Rok Zitko GND

Id: 8/10 Title: PP_PMOD: GPIO shield for DE10-Nano

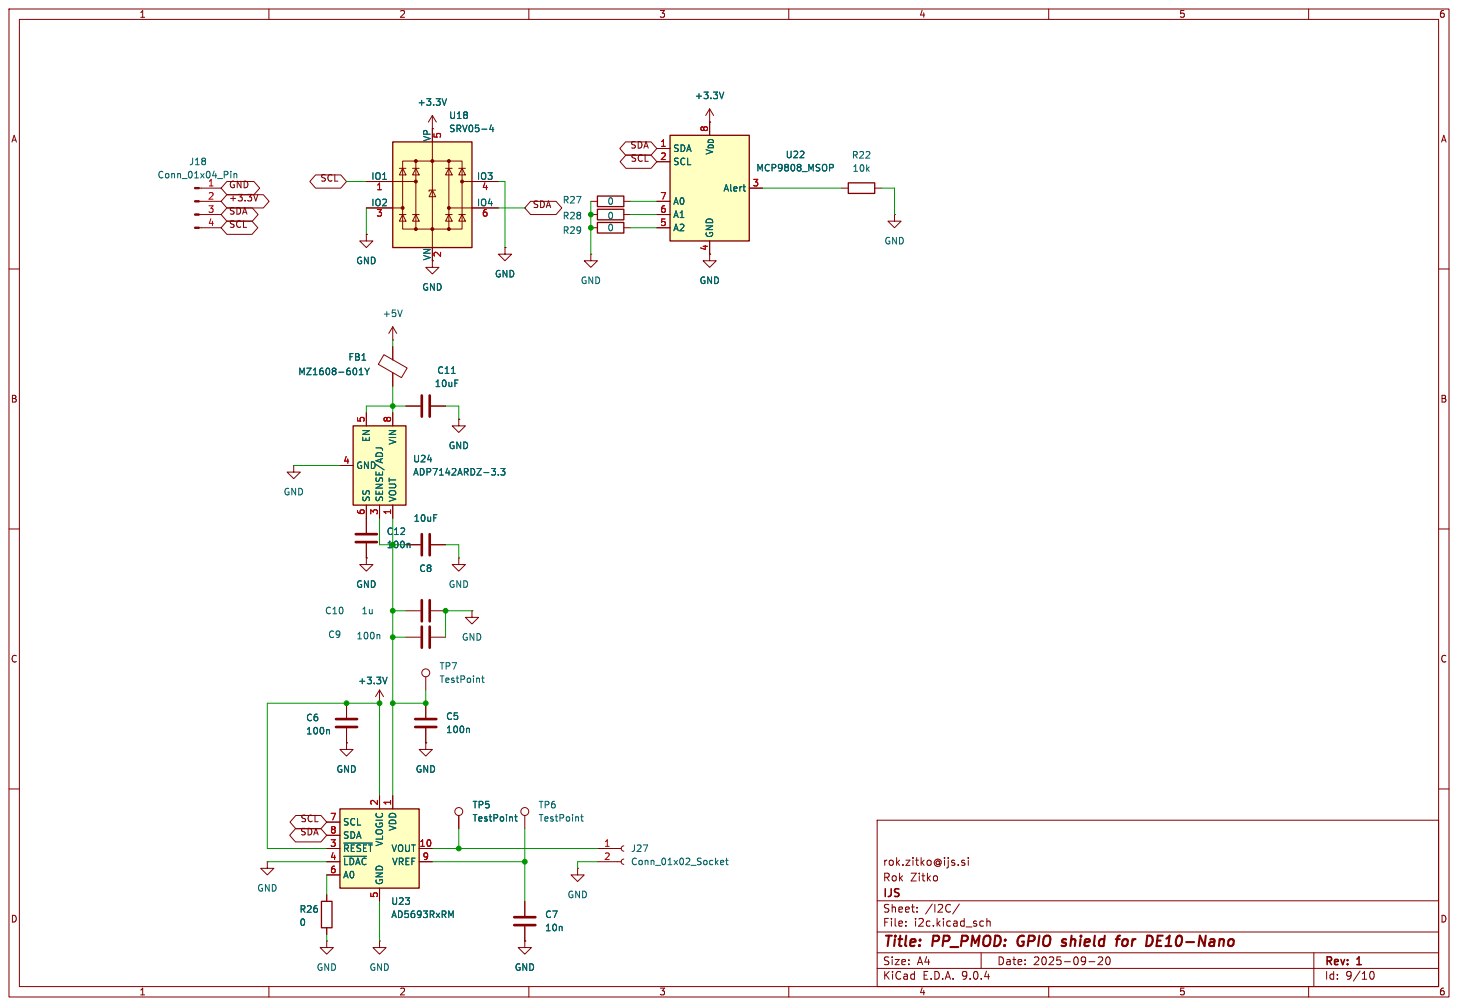
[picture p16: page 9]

rok.zitko@ijs.si GND

File: i2c.kicad_sch Sheet: /I2C/
Id: 9/10 Title: PP_PMOD: GPIO shield for DE10-Nano

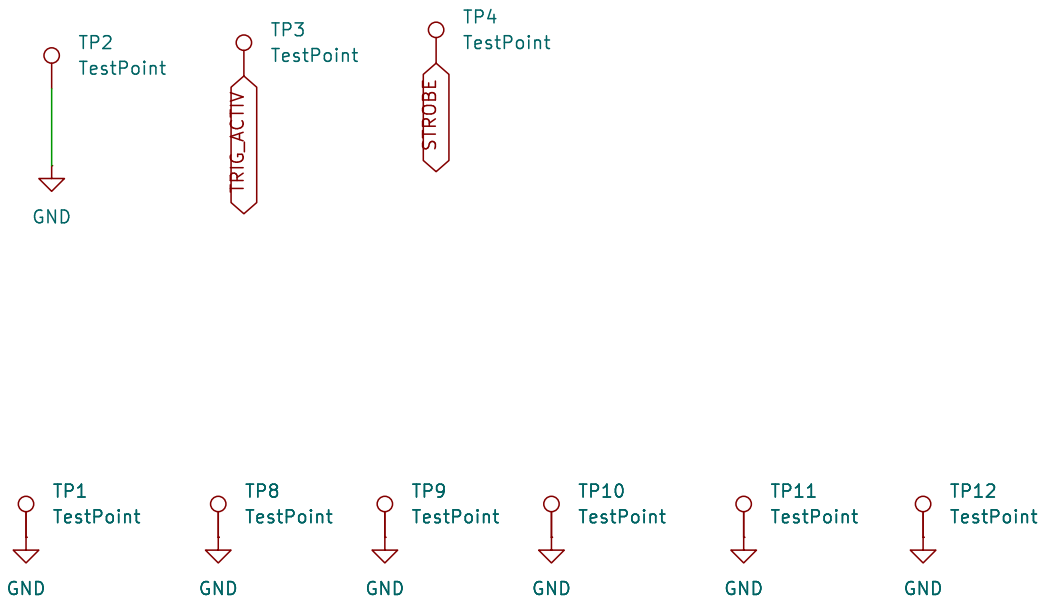
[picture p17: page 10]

File: misc.kicad_sch Sheet: /Misc/
Id: 10/10 Title: PP_PMOD: GPIO shield for DE10-Nano

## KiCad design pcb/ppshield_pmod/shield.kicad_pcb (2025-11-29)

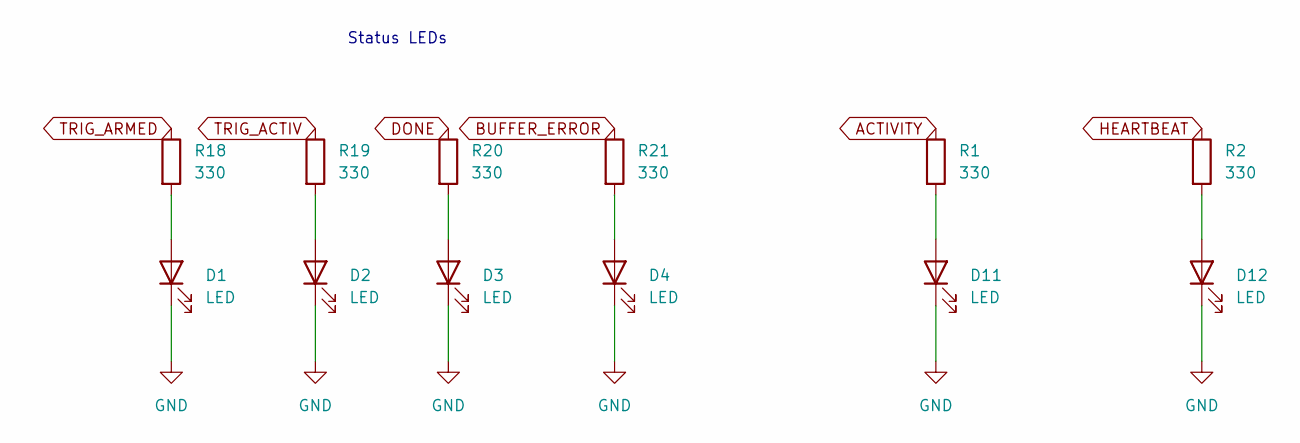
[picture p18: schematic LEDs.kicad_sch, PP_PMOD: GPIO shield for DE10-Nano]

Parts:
D1, D2, D3, D4, D11, D12: LED; LED_0603_1608Metric_Pad1.05x0.95mm_HandSolder
R1, R2, R18, R19, R20, R21: 330; R_0603_1608Metric_Pad0.98x0.95mm_HandSolder

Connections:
ACTIVITY: R1.1; also elsewhere on the board
BUFFER_ERROR: R21.1; also elsewhere on the board
DONE: R20.1; also elsewhere on the board
GND: D1.1 (K), D2.1 (K), D3.1 (K), D4.1 (K), D11.1 (K), D12.1 (K); also elsewhere on the board
HEARTBEAT: R2.1; also elsewhere on the board
unnamed: D1.2 (A), R18.2
unnamed: D2.2 (A), R19.2
unnamed: D3.2 (A), R20.2
unnamed: D4.2 (A), R21.2
unnamed: D11.2 (A), R1.2
unnamed: D12.2 (A), R2.2
TRIG_ACTIV: R19.1; also elsewhere on the board
TRIG_ARMED: R18.1; also elsewhere on the board

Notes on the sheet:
Status LEDs

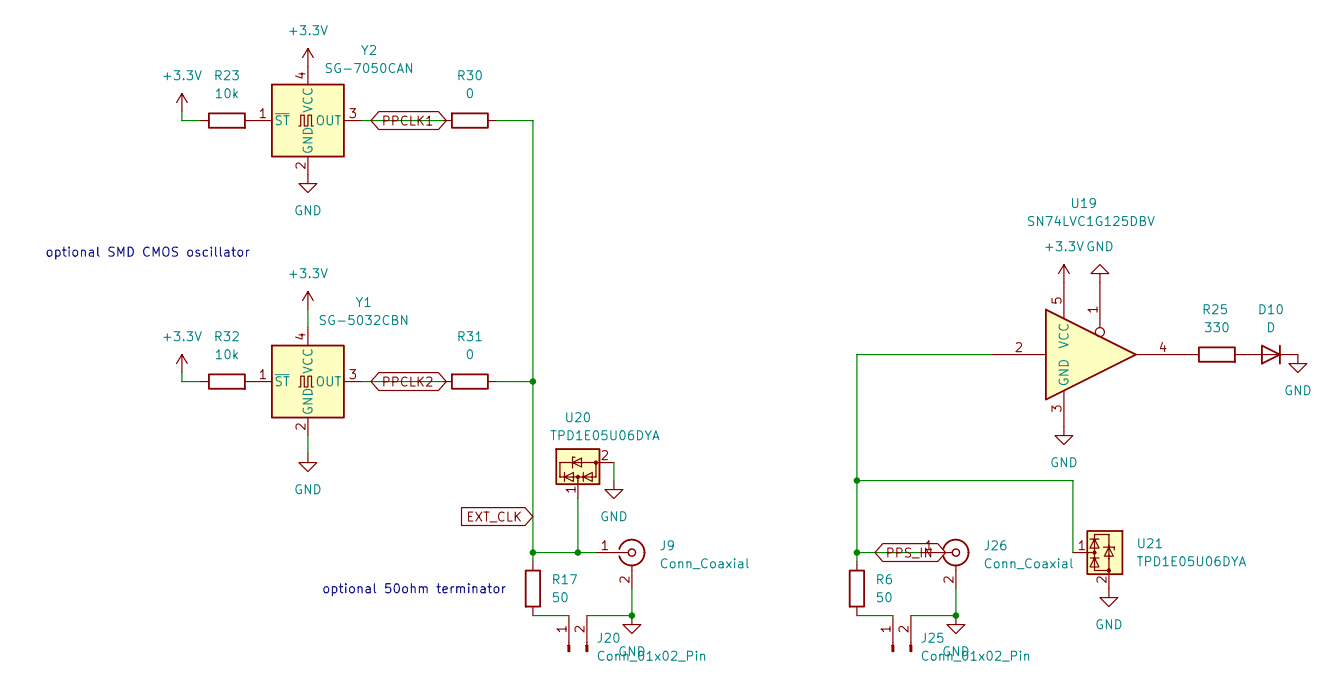
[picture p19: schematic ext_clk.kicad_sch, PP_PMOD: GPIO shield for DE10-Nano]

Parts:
D10: D; LED_0603_1608Metric_Pad1.05x0.95mm_HandSolder
J9, J26: Conn_Coaxial; SMA_Amphenol_132134-16_Vertical
J20, J25: Conn_01x02_Pin; PinHeader_1x02_P2.00mm_Vertical
R6, R17: 50; R_0603_1608Metric_Pad0.98x0.95mm_HandSolder
R23, R32: 10k; R_0603_1608Metric_Pad0.98x0.95mm_HandSolder
R25: 330; R_0603_1608Metric_Pad0.98x0.95mm_HandSolder
R30, R31: 0; R_0402_1005Metric_Pad0.72x0.64mm_HandSolder
U19: SN74LVC1G125DBV; SOT-23-5
U20, U21: TPD1E05U06DYA; D_SOD-523
Y1: SG-5032CBN; Crystal_SMD_5032-4Pin_5.0x3.2mm
Y2: SG-7050CAN; Oscillator_SMD_SeikoEpson_SG8002CA-4Pin_7.0x5.0mm

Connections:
+3.3V: R23.1, R32.1, U19.5 (VCC), Y1.4 (VCC), Y2.4 (VCC); also elsewhere on the board
EXT_CLK: J9.1 (In), R17.1, R30.1, R31.1, U20.1 (I/O); also elsewhere on the board
GND: D10.1 (K), J9.2 (Ext), J20.2, J25.2, J26.2 (Ext), U19.1, U19.3 (GND), U20.2 (GND), U21.2 (GND), Y1.2 (GND), Y2.2 (GND); also elsewhere on the board
unnamed: D10.2 (A), R25.2
unnamed: J20.1, R17.2
unnamed: J25.1, R6.2
unnamed: R25.1, U19.4
unnamed: R32.2, Y1.1 (~ST)
unnamed: R23.2, Y2.1 (~ST)
PPCLK1: R30.2, Y2.3 (OUT); also elsewhere on the board
PPCLK2: R31.2, Y1.3 (OUT); also elsewhere on the board
PPS_IN: J26.1 (In), R6.1, U19.2, U21.1 (I/O); also elsewhere on the board

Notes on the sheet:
optional 50ohm terminator
optional SMD CMOS oscillator

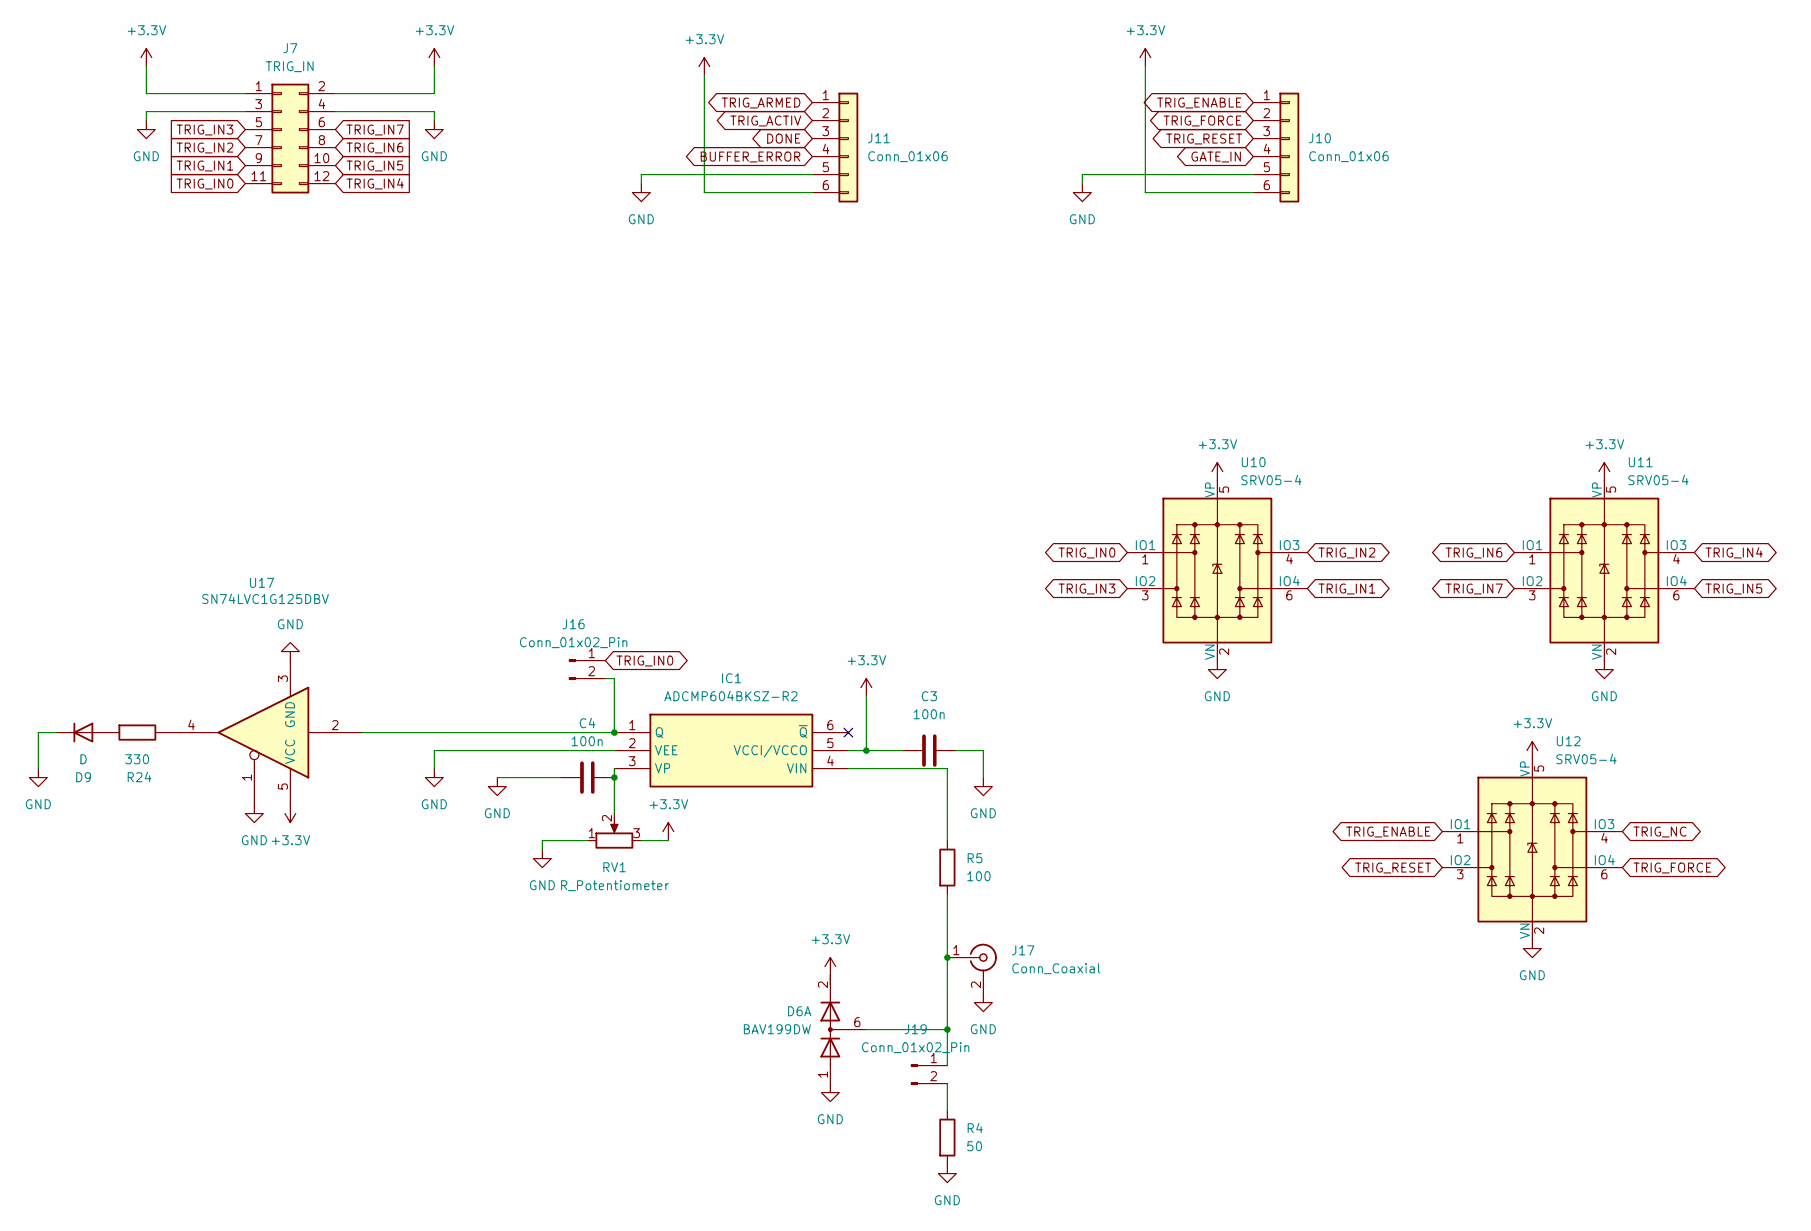
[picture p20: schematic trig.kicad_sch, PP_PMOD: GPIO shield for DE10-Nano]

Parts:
C3, C4: 100n; C_0603_1608Metric_Pad1.08x0.95mm_HandSolder
D6: BAV199DW; SOT-363_SC-70-6
D9: D; LED_0603_1608Metric_Pad1.05x0.95mm_HandSolder
IC1: ADCMP604BKSZ-R2; SOT-363_SC-70-6_Handsoldering; Manufacturer_Part_Number ADCMP604BKSZ-R2; Mouser Part Number 584-ADCMP604BKSZ-R2
J7: TRIG_IN; PinSocket_2x06_P2.54mm_Horizontal
J10, J11: Conn_01x06; PinSocket_1x06_P2.54mm_Vertical
J16: Conn_01x02_Pin; PinHeader_1x02_P2.54mm_Vertical
J17: Conn_Coaxial; SMA_Amphenol_132134-16_Vertical
J19: Conn_01x02_Pin; PinHeader_1x02_P2.00mm_Vertical
R4: 50; R_0603_1608Metric_Pad0.98x0.95mm_HandSolder
R5: 100; R_0603_1608Metric_Pad0.98x0.95mm_HandSolder
R24: 330; R_0603_1608Metric_Pad0.98x0.95mm_HandSolder
RV1: R_Potentiometer; Potentiometer_Bourns_3266P_Horizontal
U10, U11, U12: SRV05-4; SOT-23-6
U17: SN74LVC1G125DBV; SOT-23-5

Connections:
+3.3V: C3.1, D6.2 (K2), IC1.5 (VCCI/VCCO), J7.1, J7.2, J10.6, J11.6, RV1.3, U10.5 (VP), U11.5 (VP), U12.5 (VP), U17.5 (VCC); also elsewhere on the board
BUFFER_ERROR: J11.4; also elsewhere on the board
DONE: J11.3; also elsewhere on the board
GND: C3.2, C4.1, D6.1 (A1), D9.1 (K), IC1.2 (VEE), J7.3, J7.4, J10.5, J11.5, J17.2 (Ext), R4.2, RV1.1, U10.2 (VN), U11.2 (VN), U12.2 (VN), U17.1, U17.3 (GND); also elsewhere on the board
unnamed: D6.6 (K3A4), J17.1 (In), J19.1, R5.2
unnamed: D9.2 (A), R24.2
unnamed: IC1.1 (Q), J16.2, U17.2
unnamed: IC1.4 (VIN), R5.1
unnamed: C4.2, IC1.3 (VP), RV1.2
unnamed: J19.2, R4.1
unnamed: R24.1, U17.4
TRIG_ACTIV: J11.2; also elsewhere on the board
TRIG_ARMED: J11.1; also elsewhere on the board
TRIG_IN0: J7.11, J16.1, U10.1 (IO1); also elsewhere on the board
TRIG_IN1: J7.9, U10.6 (IO4); also elsewhere on the board
TRIG_IN2: J7.7, U10.4 (IO3); also elsewhere on the board
TRIG_IN3: J7.5, U10.3 (IO2); also elsewhere on the board
TRIG_IN4: J7.12, U11.4 (IO3); also elsewhere on the board
TRIG_IN5: J7.10, U11.6 (IO4); also elsewhere on the board
TRIG_IN6: J7.8, U11.1 (IO1); also elsewhere on the board
TRIG_IN7: J7.6, U11.3 (IO2); also elsewhere on the board
TRIG_RESET: J10.3, U12.3 (IO2); also elsewhere on the board

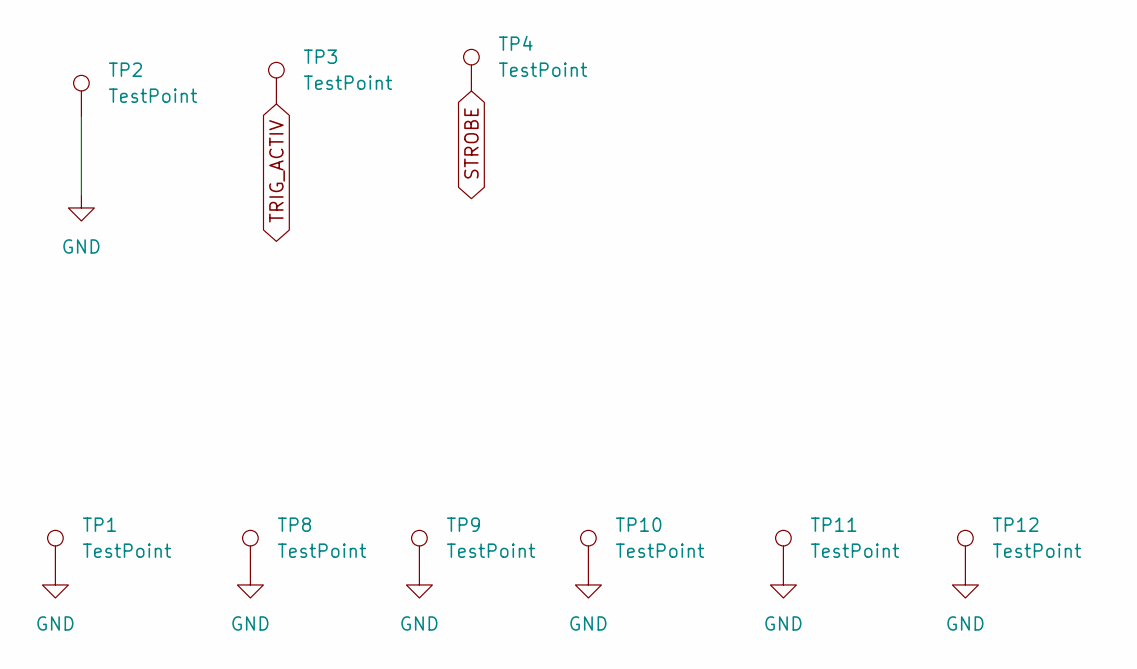
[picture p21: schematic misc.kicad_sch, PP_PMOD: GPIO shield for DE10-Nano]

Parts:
TP1, TP8, TP9, TP10, TP11, TP12: TestPoint; TestPoint_THTPad_D2.0mm_Drill1.0mm
TP2, TP3, TP4: TestPoint; TestPoint_Loop_D1.80mm_Drill1.0mm_Beaded

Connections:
GND: TP1.1, TP2.1, TP8.1, TP9.1, TP10.1, TP11.1, TP12.1; also elsewhere on the board
STROBE: TP4.1; also elsewhere on the board
TRIG_ACTIV: TP3.1; also elsewhere on the board

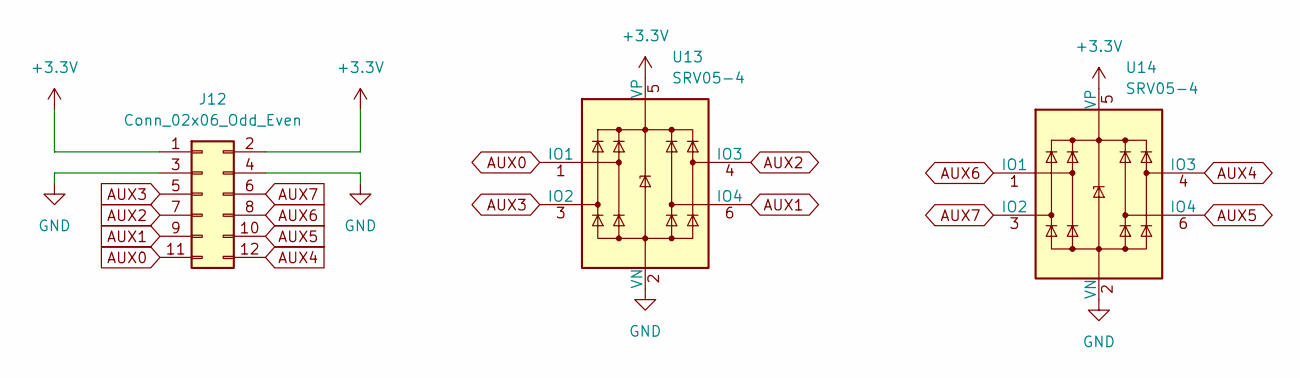
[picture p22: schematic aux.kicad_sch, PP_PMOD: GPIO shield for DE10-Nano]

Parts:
J12: Conn_02x06_Odd_Even; PinSocket_2x06_P2.54mm_Horizontal
U13, U14: SRV05-4; SOT-23-6

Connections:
+3.3V: J12.1, J12.2, U13.5 (VP), U14.5 (VP); also elsewhere on the board
AUX0: J12.11, U13.1 (IO1); also elsewhere on the board
AUX1: J12.9, U13.6 (IO4); also elsewhere on the board
AUX2: J12.7, U13.4 (IO3); also elsewhere on the board
AUX3: J12.5, U13.3 (IO2); also elsewhere on the board
AUX4: J12.12, U14.4 (IO3); also elsewhere on the board
AUX5: J12.10, U14.6 (IO4); also elsewhere on the board
AUX6: J12.8, U14.1 (IO1); also elsewhere on the board
AUX7: J12.6, U14.3 (IO2); also elsewhere on the board
GND: J12.3, J12.4, U13.2 (VN), U14.2 (VN); also elsewhere on the board

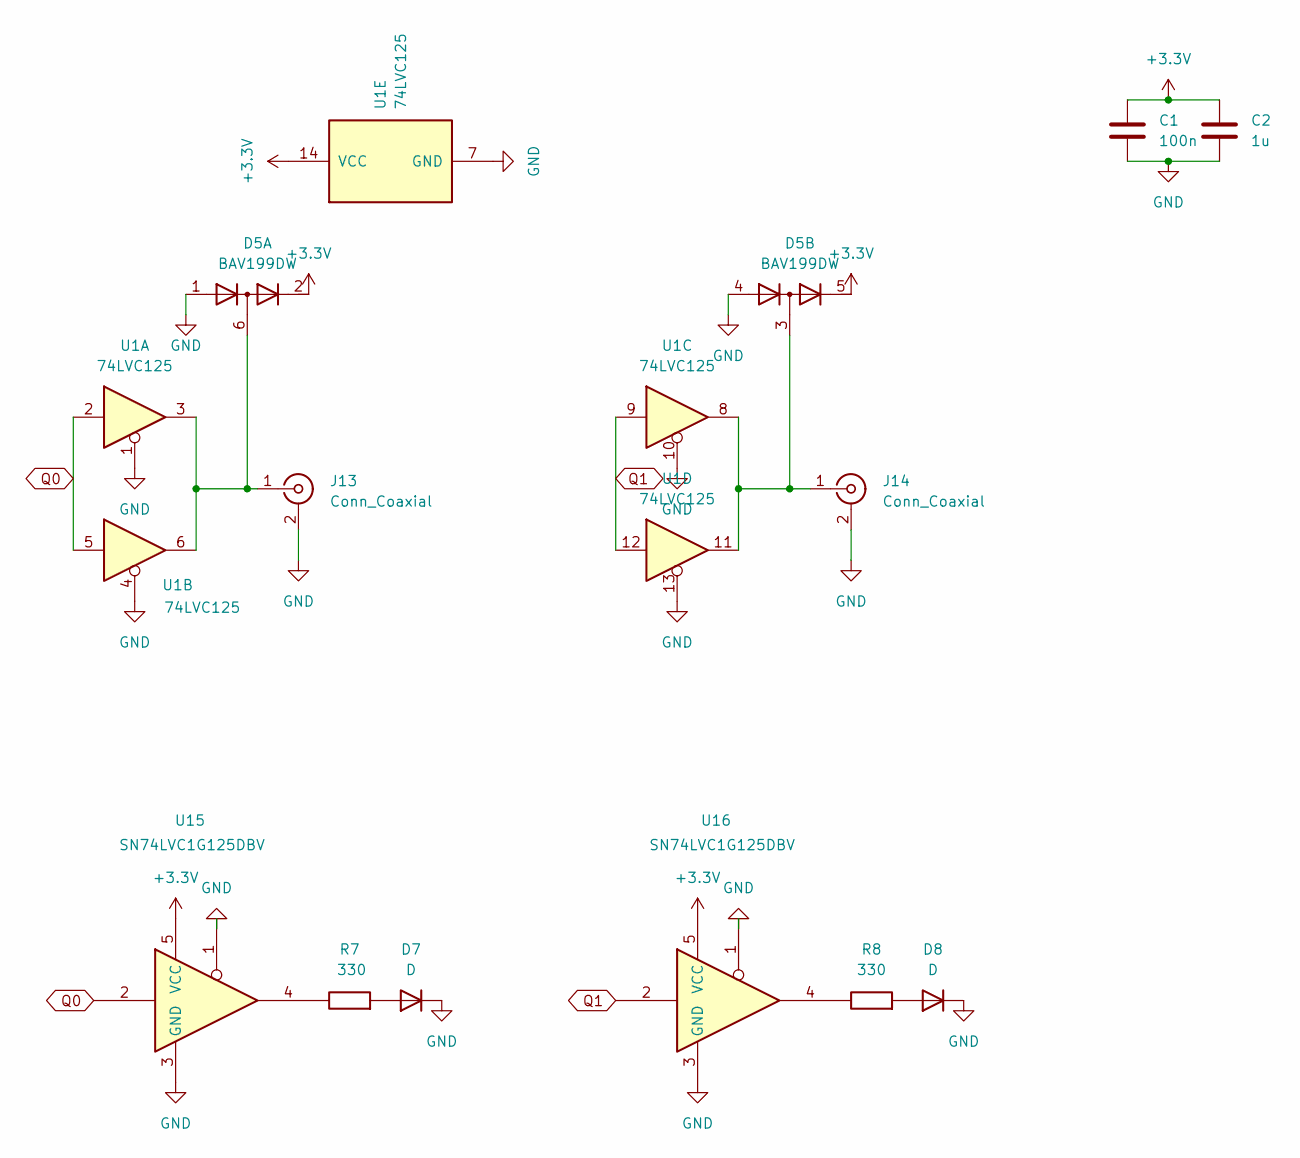
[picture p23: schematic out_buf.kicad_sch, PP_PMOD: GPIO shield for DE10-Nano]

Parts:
C1: 100n; C_0603_1608Metric_Pad1.08x0.95mm_HandSolder
C2: 1u; C_0603_1608Metric_Pad1.08x0.95mm_HandSolder
D5: BAV199DW; SOT-363_SC-70-6
D7, D8: D; LED_0603_1608Metric_Pad1.05x0.95mm_HandSolder
J13, J14: Conn_Coaxial; SMA_Amphenol_132134-16_Vertical
R7, R8: 330; R_0603_1608Metric_Pad0.98x0.95mm_HandSolder
U1: 74LVC125; SOIC-14_3.9x8.7mm_P1.27mm
U15, U16: SN74LVC1G125DBV; SOT-23-5

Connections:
+3.3V: C1.1, C2.1, D5.2 (K2), D5.5 (K4), U1.14 (VCC), U15.5 (VCC), U16.5 (VCC); also elsewhere on the board
GND: C1.2, C2.2, D5.1 (A1), D5.4 (A3), D7.1 (K), D8.1 (K), J13.2 (Ext), J14.2 (Ext), U1.1, U1.4, U1.7 (GND), U1.10, U1.13, U15.1, U15.3 (GND), U16.1, U16.3 (GND); also elsewhere on the board
unnamed: D5.6 (K3A4), J13.1 (In), U1.3, U1.6
unnamed: D5.3 (K1A2), J14.1 (In), U1.8, U1.11
unnamed: D7.2 (A), R7.2
unnamed: D8.2 (A), R8.2
unnamed: R7.1, U15.4
unnamed: R8.1, U16.4
Q0: U1.2, U1.5, U15.2; also elsewhere on the board
Q1: U1.9, U1.12, U16.2; also elsewhere on the board

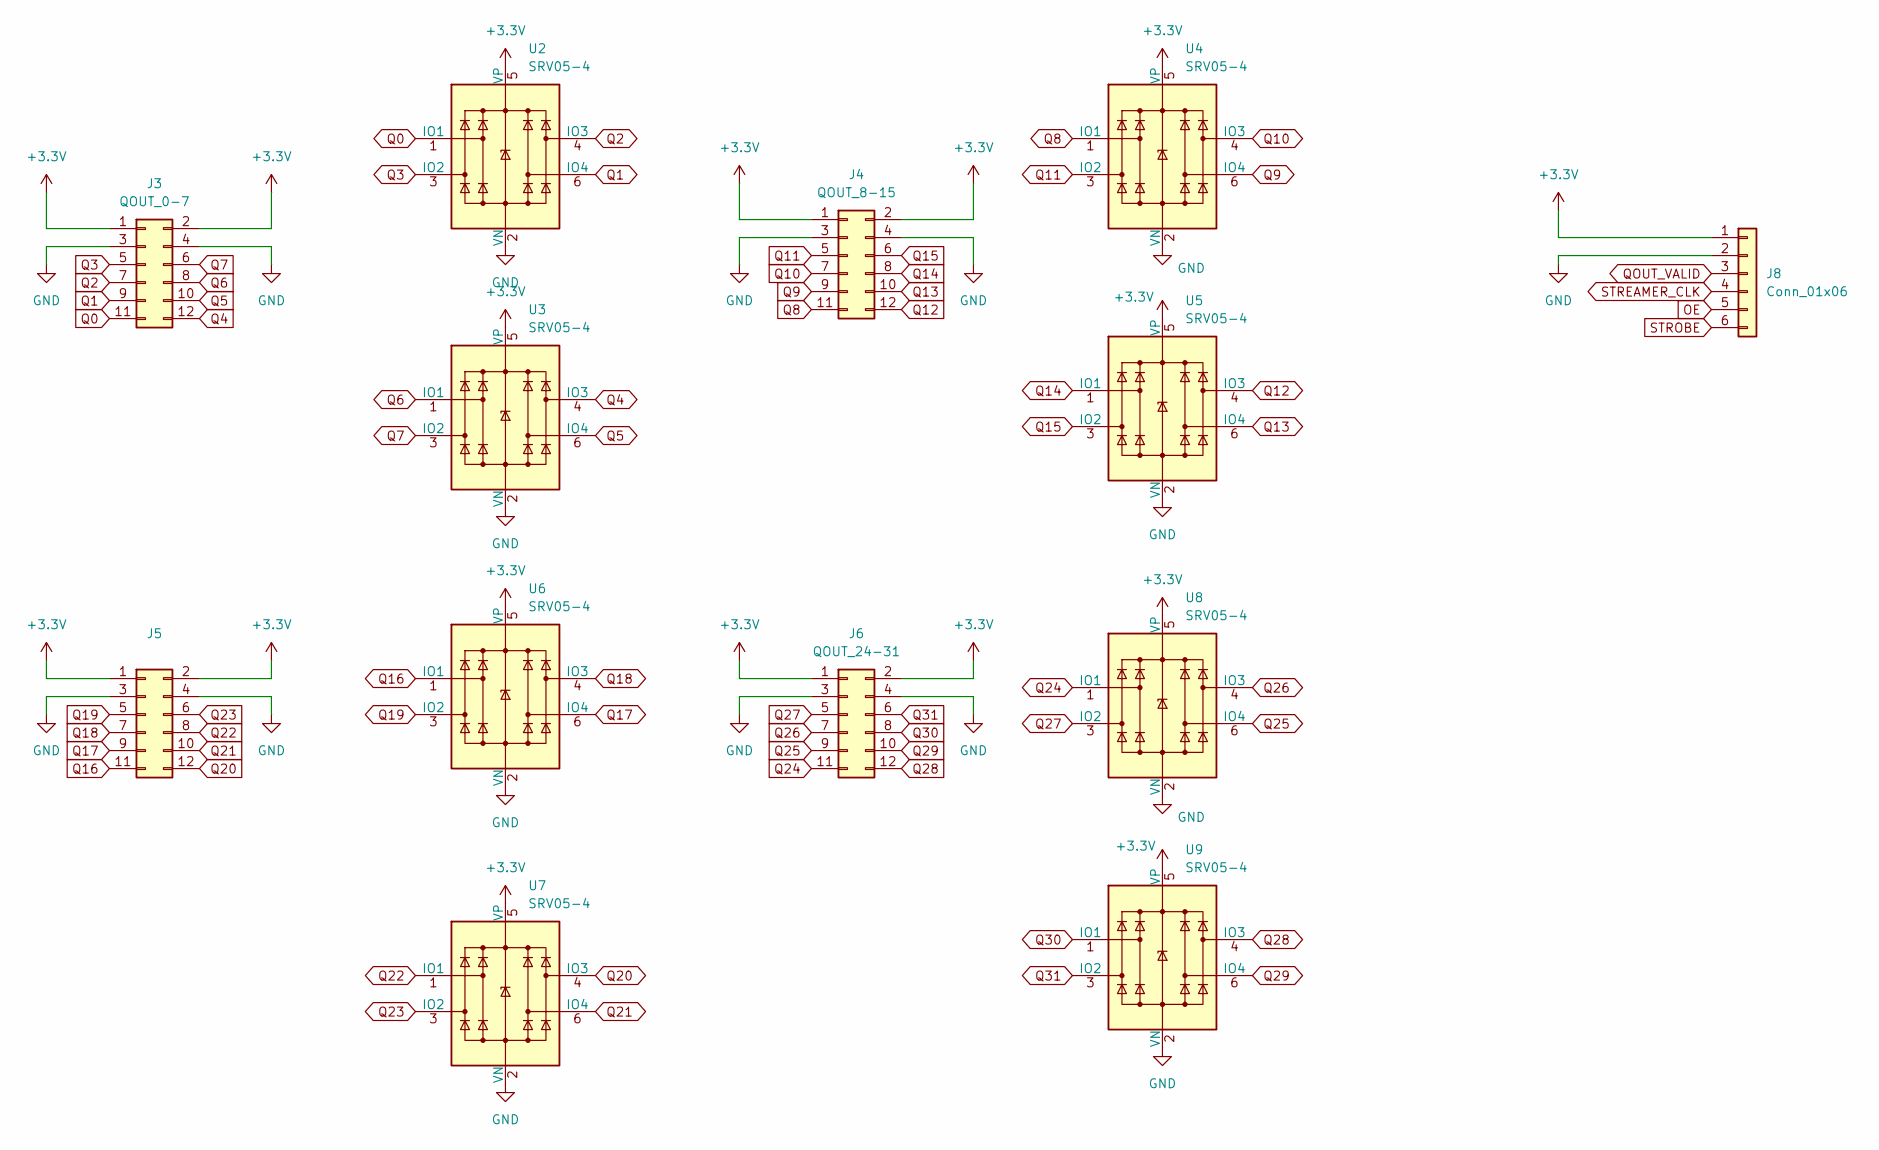
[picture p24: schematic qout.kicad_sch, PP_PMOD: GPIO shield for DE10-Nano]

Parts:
J3: QOUT_0-7; PinSocket_2x06_P2.54mm_Horizontal
J4: QOUT_8-15; PinSocket_2x06_P2.54mm_Horizontal
J5: QOUT_16-23; PinSocket_2x06_P2.54mm_Horizontal
J6: QOUT_24-31; PinSocket_2x06_P2.54mm_Horizontal
J8: Conn_01x06; PinSocket_1x06_P2.54mm_Horizontal
U2, U3, U4, U5, U6, U7, U8, U9: SRV05-4; SOT-23-6

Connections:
+3.3V: J3.1, J3.2, J4.1, J4.2, J5.1, J5.2, J6.1, J6.2, J8.1, U2.5 (VP), U3.5 (VP), U4.5 (VP), U5.5 (VP), U6.5 (VP), U7.5 (VP), U8.5 (VP), U9.5 (VP); also elsewhere on the board
GND: J3.3, J3.4, J4.3, J4.4, J5.3, J5.4, J6.3, J6.4, J8.2, U2.2 (VN), U3.2 (VN), U4.2 (VN), U5.2 (VN), U6.2 (VN), U7.2 (VN), U8.2 (VN), U9.2 (VN); also elsewhere on the board
OE: J8.5; also elsewhere on the board
Q0: J3.11, U2.1 (IO1); also elsewhere on the board
Q1: J3.9, U2.6 (IO4); also elsewhere on the board
Q2: J3.7, U2.4 (IO3); also elsewhere on the board
Q3: J3.5, U2.3 (IO2); also elsewhere on the board
Q4: J3.12, U3.4 (IO3); also elsewhere on the board
Q5: J3.10, U3.6 (IO4); also elsewhere on the board
Q6: J3.8, U3.1 (IO1); also elsewhere on the board
Q7: J3.6, U3.3 (IO2); also elsewhere on the board
Q8: J4.11, U4.1 (IO1); also elsewhere on the board
Q9: J4.9, U4.6 (IO4); also elsewhere on the board
Q10: J4.7, U4.4 (IO3); also elsewhere on the board
Q11: J4.5, U4.3 (IO2); also elsewhere on the board
Q12: J4.12, U5.4 (IO3); also elsewhere on the board
Q13: J4.10, U5.6 (IO4); also elsewhere on the board
Q14: J4.8, U5.1 (IO1); also elsewhere on the board
Q15: J4.6, U5.3 (IO2); also elsewhere on the board
Q16: J5.11, U6.1 (IO1); also elsewhere on the board
Q17: J5.9, U6.6 (IO4); also elsewhere on the board
Q18: J5.7, U6.4 (IO3); also elsewhere on the board
Q19: J5.5, U6.3 (IO2); also elsewhere on the board
Q20: J5.12, U7.4 (IO3); also elsewhere on the board
Q21: J5.10, U7.6 (IO4); also elsewhere on the board
Q22: J5.8, U7.1 (IO1); also elsewhere on the board
Q23: J5.6, U7.3 (IO2); also elsewhere on the board
Q24: J6.11, U8.1 (IO1); also elsewhere on the board
Q25: J6.9, U8.6 (IO4); also elsewhere on the board
Q26: J6.7, U8.4 (IO3); also elsewhere on the board
Q27: J6.5, U8.3 (IO2); also elsewhere on the board
Q28: J6.12, U9.4 (IO3); also elsewhere on the board
Q29: J6.10, U9.6 (IO4); also elsewhere on the board
Q30: J6.8, U9.1 (IO1); also elsewhere on the board
Q31: J6.6, U9.3 (IO2); also elsewhere on the board
QOUT_VALID: J8.3; also elsewhere on the board
STREAMER_CLK: J8.4; also elsewhere on the board
STROBE: J8.6; also elsewhere on the board

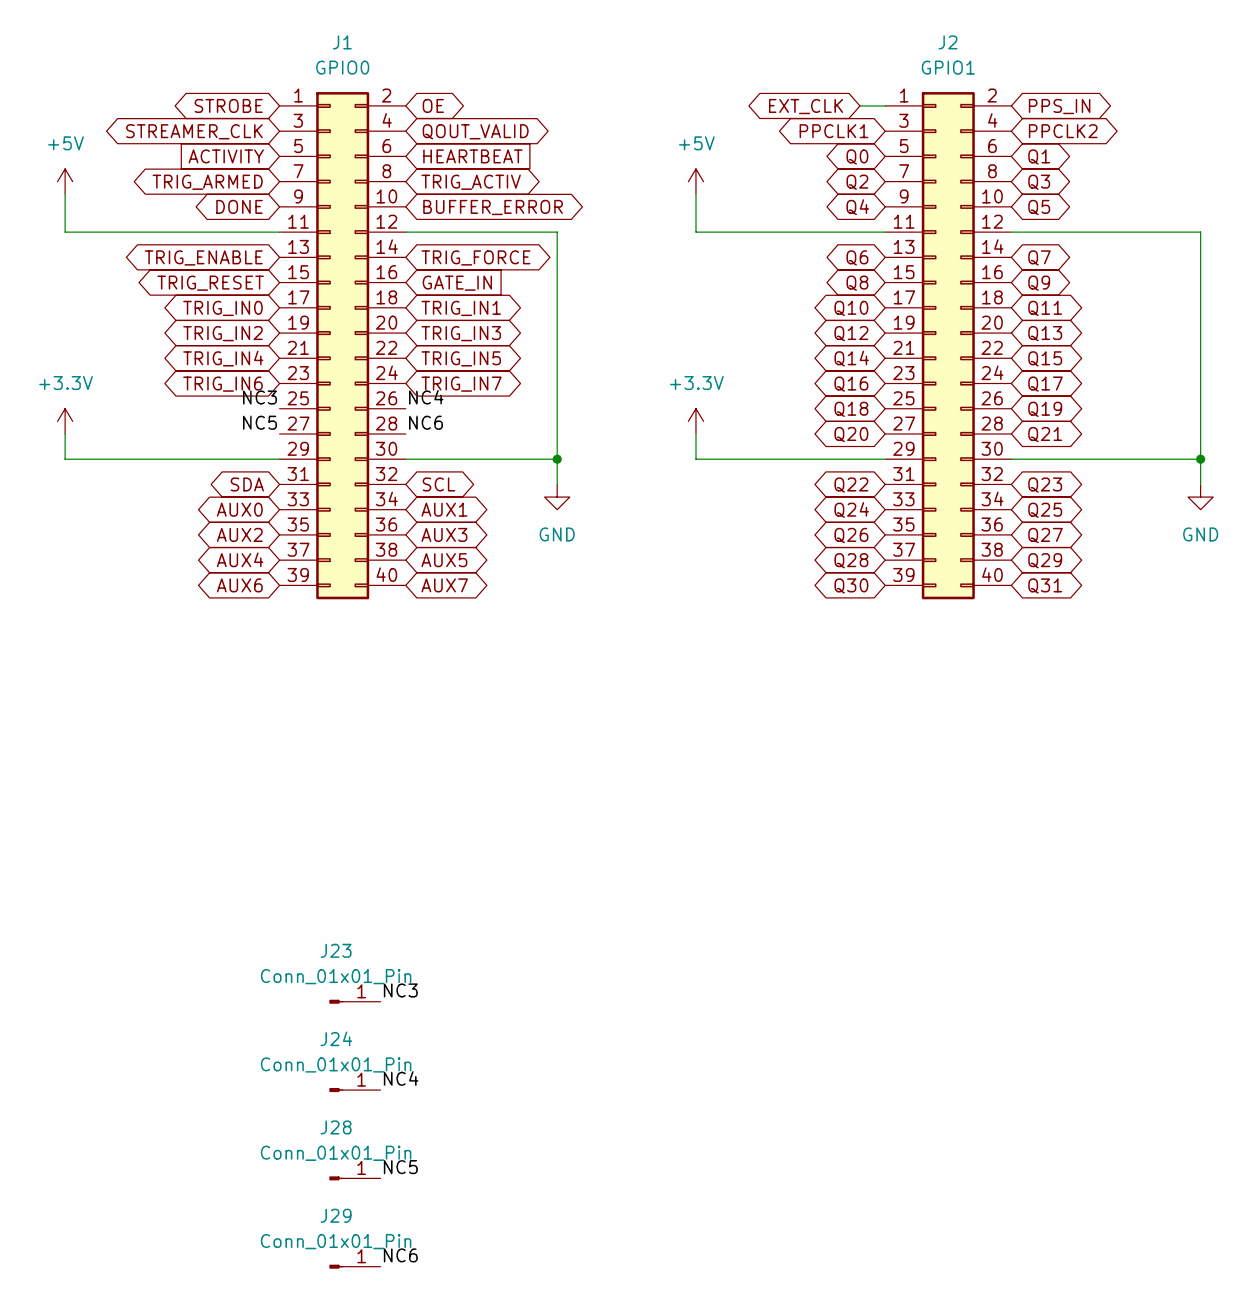
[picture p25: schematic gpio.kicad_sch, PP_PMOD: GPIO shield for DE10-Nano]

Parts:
J1: GPIO0; PinSocket_2x20_P2.54mm_Vertical
J2: GPIO1; PinSocket_2x20_P2.54mm_Vertical
J23, J24, J28, J29: Conn_01x01_Pin; TestPoint_THTPad_1.5x1.5mm_Drill0.7mm

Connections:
+3.3V: J1.29, J2.29; also elsewhere on the board
+5V: J1.11, J2.11; also elsewhere on the board
/GPIO/NC3: J1.25, J23.1
/GPIO/NC4: J1.26, J24.1
/GPIO/NC5: J1.27, J28.1
/GPIO/NC6: J1.28, J29.1
ACTIVITY: J1.5; also elsewhere on the board
AUX0: J1.33; also elsewhere on the board
AUX1: J1.34; also elsewhere on the board
AUX2: J1.35; also elsewhere on the board
AUX3: J1.36; also elsewhere on the board
AUX4: J1.37; also elsewhere on the board
AUX5: J1.38; also elsewhere on the board
AUX6: J1.39; also elsewhere on the board
AUX7: J1.40; also elsewhere on the board
BUFFER_ERROR: J1.10; also elsewhere on the board
DONE: J1.9; also elsewhere on the board
EXT_CLK: J2.1; also elsewhere on the board
GND: J1.12, J1.30, J2.12, J2.30; also elsewhere on the board
HEARTBEAT: J1.6; also elsewhere on the board
OE: J1.2; also elsewhere on the board
PPCLK1: J2.3; also elsewhere on the board
PPCLK2: J2.4; also elsewhere on the board
PPS_IN: J2.2; also elsewhere on the board
Q0: J2.5; also elsewhere on the board
Q1: J2.6; also elsewhere on the board
Q2: J2.7; also elsewhere on the board
Q3: J2.8; also elsewhere on the board
Q4: J2.9; also elsewhere on the board
Q5: J2.10; also elsewhere on the board
Q6: J2.13; also elsewhere on the board
Q7: J2.14; also elsewhere on the board
Q8: J2.15; also elsewhere on the board
Q9: J2.16; also elsewhere on the board
Q10: J2.17; also elsewhere on the board
Q11: J2.18; also elsewhere on the board
Q12: J2.19; also elsewhere on the board
Q13: J2.20; also elsewhere on the board
Q14: J2.21; also elsewhere on the board
Q15: J2.22; also elsewhere on the board
Q16: J2.23; also elsewhere on the board
Q17: J2.24; also elsewhere on the board
Q18: J2.25; also elsewhere on the board
Q19: J2.26; also elsewhere on the board
Q20: J2.27; also elsewhere on the board
Q21: J2.28; also elsewhere on the board
Q22: J2.31; also elsewhere on the board
Q23: J2.32; also elsewhere on the board
Q24: J2.33; also elsewhere on the board
Q25: J2.34; also elsewhere on the board
Q26: J2.35; also elsewhere on the board
Q27: J2.36; also elsewhere on the board
Q28: J2.37; also elsewhere on the board
Q29: J2.38; also elsewhere on the board
Q30: J2.39; also elsewhere on the board
Q31: J2.40; also elsewhere on the board
QOUT_VALID: J1.4; also elsewhere on the board
SCL: J1.32; also elsewhere on the board
SDA: J1.31; also elsewhere on the board
STREAMER_CLK: J1.3; also elsewhere on the board
STROBE: J1.1; also elsewhere on the board
TRIG_ACTIV: J1.8; also elsewhere on the board
TRIG_ARMED: J1.7; also elsewhere on the board
TRIG_IN0: J1.17; also elsewhere on the board
TRIG_IN1: J1.18; also elsewhere on the board
TRIG_IN2: J1.19; also elsewhere on the board
TRIG_IN3: J1.20; also elsewhere on the board
TRIG_IN4: J1.21; also elsewhere on the board
TRIG_IN5: J1.22; also elsewhere on the board
TRIG_IN6: J1.23; also elsewhere on the board
TRIG_IN7: J1.24; also elsewhere on the board
TRIG_RESET: J1.15; also elsewhere on the board

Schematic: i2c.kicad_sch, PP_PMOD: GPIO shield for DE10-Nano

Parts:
C5, C6, C9: 100n; C_0603_1608Metric_Pad1.08x0.95mm_HandSolder
C7: 10n; C_0603_1608Metric_Pad1.08x0.95mm_HandSolder
C8, C11: 10uF; C_0805_2012Metric_Pad1.18x1.45mm_HandSolder
C10: 1u; C_0603_1608Metric_Pad1.08x0.95mm_HandSolder
C12: 100n; R_0603_1608Metric_Pad0.98x0.95mm_HandSolder
FB1: MZ1608-601Y; L_0603_1608Metric_Pad1.05x0.95mm_HandSolder
J18: Conn_01x04_Pin; JST_SH_SM04B-SRSS-TB_1x04-1MP_P1.00mm_Horizontal
J27: Conn_01x02_Socket; JST_SH_BM02B-SRSS-TB_1x02-1MP_P1.00mm_Vertical
R22: 10k; R_0603_1608Metric_Pad0.98x0.95mm_HandSolder
R26: 0; C_0402_1005Metric_Pad0.74x0.62mm_HandSolder
R27, R28, R29: 0; R_0402_1005Metric_Pad0.72x0.64mm_HandSolder
TP5, TP6, TP7: TestPoint; TestPoint_Pad_D1.0mm
U18: SRV05-4; SOT-23-6
U22: MCP9808_MSOP; MSOP-8_3x3mm_P0.65mm
U23: AD5693RxRM; MSOP-10_3x3mm_P0.5mm
U24: ADP7142ARDZ-3.3; SOIC-8-1EP_3.9x4.9mm_P1.27mm_EP2.29x3mm

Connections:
+3.3V: C6.1, J18.2, U18.5 (VP), U22.8 (V_{DD}), U23.2 (VLOGIC), U23.3 (~RESET); also elsewhere on the board
+5V: FB1.1; also elsewhere on the board
GND: C5.2, C6.2, C7.2, C8.2, C9.2, C10.2, C11.2, C12.2, J18.1, J27.2, R22.2, R26.2, R27.1, R28.1, R29.1, U18.2 (VN), U18.3 (IO2), U18.4 (IO3), U22.4 (GND), U23.4 (~LDAC), U23.5 (GND), U24.4 (GND), U24.9 (GND); also elsewhere on the board
unnamed: J27.1, TP5.1, U23.10 (VOUT)
unnamed: R27.2, U22.7 (A0)
unnamed: R28.2, U22.6 (A1)
unnamed: R29.2, U22.5 (A2)
unnamed: R22.1, U22.3 (Alert)
unnamed: R26.1, U23.6 (A0)
unnamed: C5.1, C8.1, C9.1, C10.1, TP7.1, U23.1 (VDD), U24.1 (VOUT), U24.2 (VOUT), U24.3 (SENSE/ADJ)
unnamed: C7.1, TP6.1, U23.9 (VREF)
unnamed: C11.1, FB1.2, U24.5 (EN), U24.7 (VIN), U24.8 (VIN)
unnamed: C12.1, U24.6 (SS)
SCL: J18.4, U18.1 (IO1), U22.2 (SCL), U23.7 (SCL); also elsewhere on the board
SDA: J18.3, U18.6 (IO4), U22.1 (SDA), U23.8 (SDA); also elsewhere on the board

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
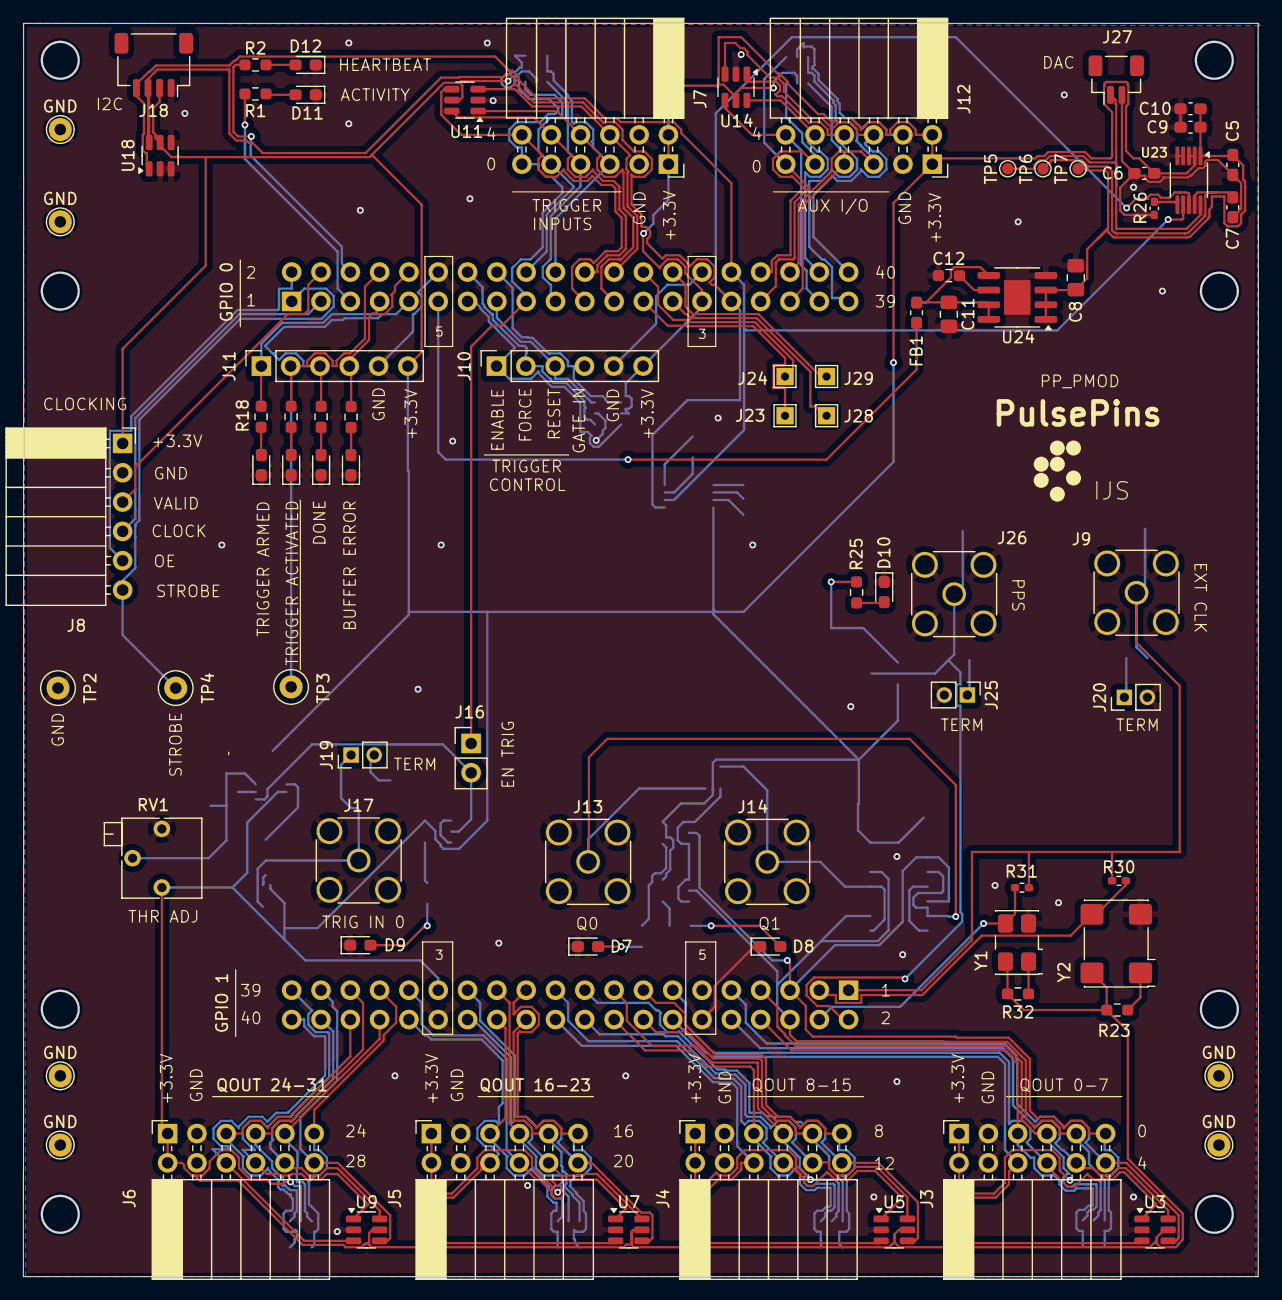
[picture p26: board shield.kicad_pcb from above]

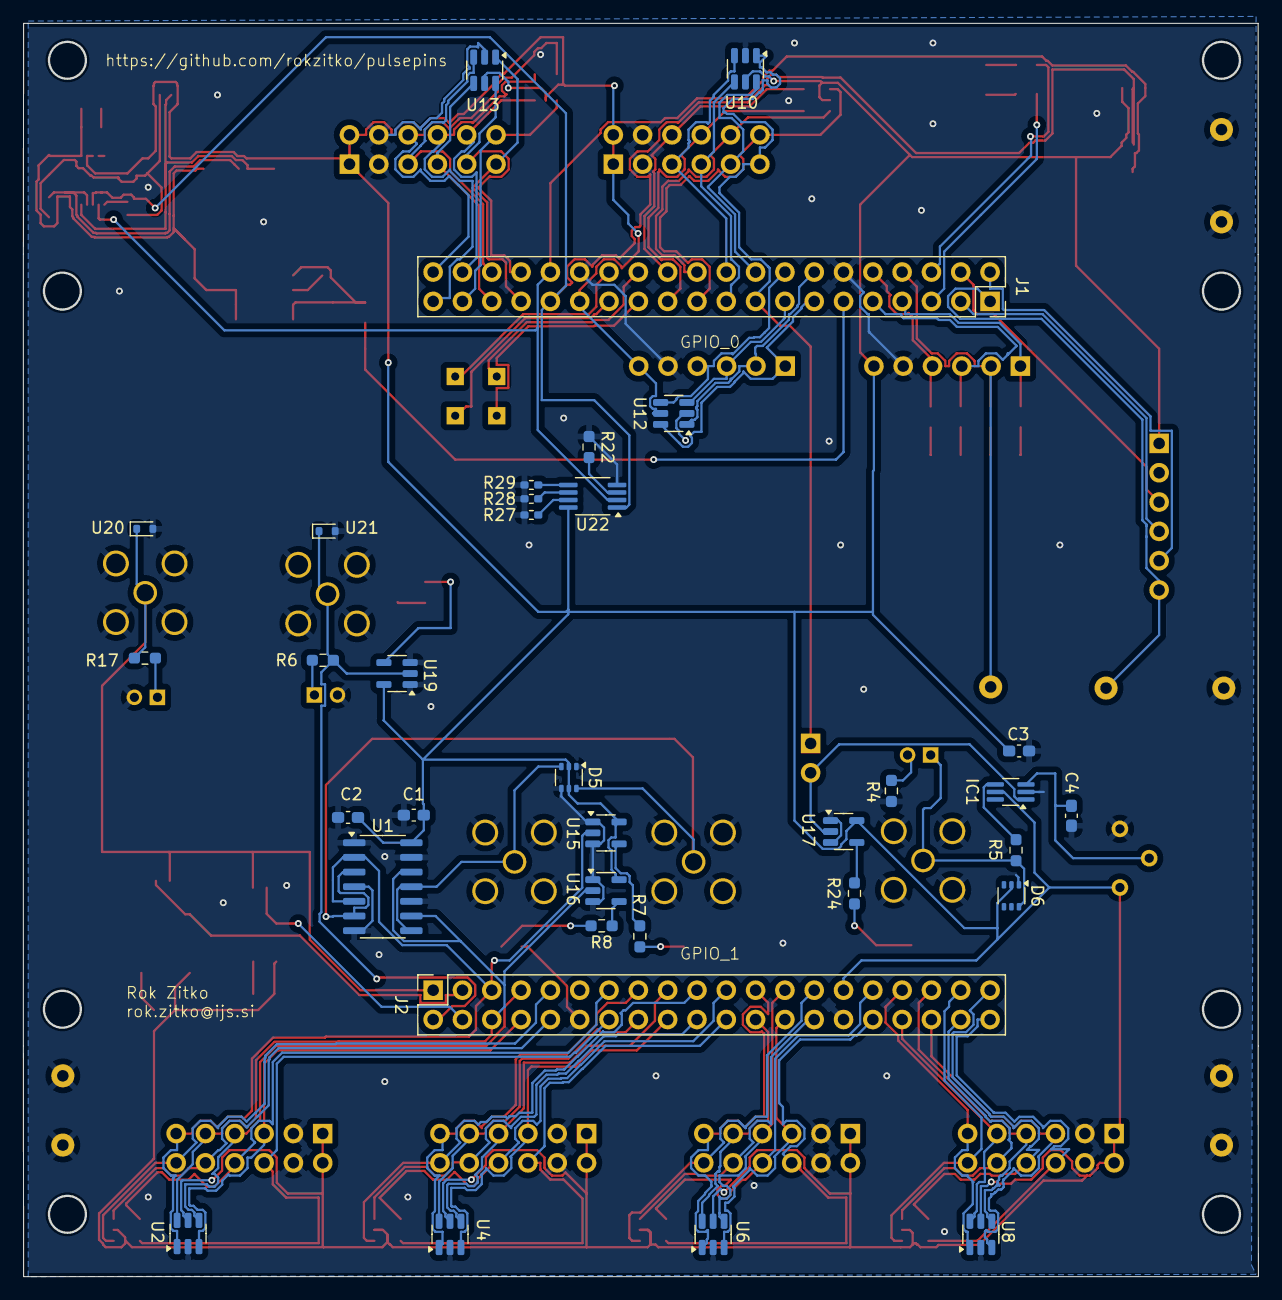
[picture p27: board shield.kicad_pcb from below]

Board: 2 copper layers, 107.0 x 108.6 mm, 114 parts (35 on the bottom side), 110 nets.

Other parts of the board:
GND: TestPoint; TestPoint_THTPad_D2.0mm_Drill1.0mm
GND#2, GND#3, GND#4, GND#5, GND#6: TestPoint; TestPoint_THTPad_D2.0mm_Drill1.0mm

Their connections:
GND: GND.1, GND#2.1, GND#3.1, GND#4.1, GND#5.1, GND#6.1; also elsewhere on the board

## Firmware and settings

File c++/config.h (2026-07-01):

// SPDX-License-Identifier: MIT
// Copyright (c) 2025 Rok Zitko

// Constants

#pragma once

#include <cstddef>
#include <cstdint>
#include <limits>

#include "misc.hh"

constexpr int P_FIFO_IN1 = 10;
constexpr int P_FIFO_IN2 = 11;
constexpr int P_FIFO_OUT = 12;
constexpr int SIZE_FIFO_IN1 = 1 << P_FIFO_IN1;
constexpr int SIZE_FIFO_IN2 = 1 << P_FIFO_IN2;
constexpr int SIZE_FIFO_OUT = 1 << P_FIFO_OUT;
constexpr int almost_shift = 16; // see input_fifo.sv

constexpr int WIDTH_AVS_BUS = 32; // port width of the AVS bus used in the streaming interface
using bus_t = uint32_t;           // corresponding C++ type
constexpr int WIDTH_PORT = 32;    // port width in bits for various FPGA interfaces
using port_t = uint32_t;          // corresponding C++ type

static_assert(sizeof(bus_t)*8 == WIDTH_AVS_BUS);
static_assert(sizeof(port_t)*8 == WIDTH_PORT);

// These must be consistent with ip/streamer/config.vh

constexpr int WIDTH_CONTROL = 32;
constexpr int WIDTH_COUNTER = 32;
constexpr int WIDTH_DATA = 32;
constexpr int WIDTH_TOTAL = WIDTH_CONTROL + WIDTH_COUNTER + WIDTH_DATA;
constexpr int BYTES_TOTAL = WIDTH_TOTAL/8;

using control_t = uint32_t; // control register data type
using count_t   = uint32_t; // counter register data type
using value_t   = uint32_t; // value data type

static_assert(sizeof(control_t)*8 == WIDTH_CONTROL);
static_assert(sizeof(count_t)*8   == WIDTH_COUNTER);
static_assert(sizeof(value_t)*8   == WIDTH_DATA);

const uint64_t max_count_t = std::numeric_limits<count_t>::max(); // for checking boundaries

using trigger_t = uint8_t;
constexpr int WIDTH_TRIGGER = 8;
constexpr int TRIGGER_MASK = 0xFF;

using aux_t = uint8_t;
constexpr int WIDTH_AUX = 8;
constexpr int AUX_MASK = 0xFF;

constexpr uint32_t CFG_STREAMER_ACTIVE_MASK_OFFSET = 13;
constexpr uint32_t CFG_STREAMER_ARMED_LIVE_MASK_OFFSET = 17;
constexpr uint32_t STREAMER_MASK_BITS = 4;
constexpr uint32_t STREAMER_MASK_VALUE_MASK = 0x0f;
constexpr uint32_t STREAMER_ACTIVE_MASK_CFG_MASK =
  STREAMER_MASK_VALUE_MASK << CFG_STREAMER_ACTIVE_MASK_OFFSET;
constexpr uint32_t STREAMER_ARMED_LIVE_MASK_CFG_MASK =
  STREAMER_MASK_VALUE_MASK << CFG_STREAMER_ARMED_LIVE_MASK_OFFSET;

// Function aliases; we need two sets due to different interfaces (_t versions accept
// a string; those without _t suffix accept InputParse, keyword, default_value)
const auto parse_value_t = parse_uint32_t;
const auto parse_count_t = parse_uint32_t;
const auto parse_trigger_t = parse_uint8_t;
const auto parse_value = parse_uint32;
const auto parse_count = parse_uint32;
const auto parse_trigger = parse_uint8;

constexpr int PIO1_ENABLE = 8;
constexpr int PIO1_FORCE  = 9;
constexpr int PIO1_RESET  = 10;

static_assert(sizeof(trigger_t)*8 == WIDTH_TRIGGER);

// control (least significant bits):
//        0 - regular element [bit 0]
//        1 - trigger element
//       01 - trigger element (part of the sequence) [bit 1]
//       11 - trigger element (last in the sequence)
//      1x0 - sequence terminator (subtype of regular data) [bit 2]
//     1xx0 - pulses without strobes [bit 3]
// 0000xxx0 - load word [bits 4-7]
// 0001xxx0 - bit set (for bit addressing)
// 0010xxx0 - bit clear (for bit addressing)
// 0011xxx0 - bit flip (for bit addressing)
// [bit 8]  - 0=pass, 1=discard/store/replay
// [bit 9]  - store
// [bit 15] - replay
// [bit 16] - retrig
// [bit 17] - random

// These must be consistent with ip/streamer/config.vh
constexpr control_t STROBE       = 0b0000;
constexpr control_t TRIGGERBITS  = 0b0011; // mask for testing the trigger condition
constexpr control_t TRIGGER      = 0b0001;
constexpr control_t TRIGGERFINAL = 0b0010;
constexpr control_t TERMINATE    = 0b0100;
constexpr control_t NOSTROBE     = 0b1000;

constexpr control_t MODEBITS     = 0b1111'0000; // mask for testing the update mode

constexpr control_t BITLOAD      = 0b0000'0000;
constexpr control_t BITSET       = 0b0001'0000;
constexpr control_t BITCLEAR     = 0b0010'0000;
constexpr control_t BITFLIP      = 0b0011'0000;

constexpr control_t BITNOT       = 0b0100'0000;
constexpr control_t BITAND       = 0b0101'0000;
constexpr control_t BITOR        = 0b0110'0000;
constexpr control_t BITXOR       = 0b0111'0000;
constexpr control_t BITXNOR      = 0b1000'0000;

constexpr control_t BITSLL       = 0b1001'0000;
constexpr control_t BITSRL       = 0b1010'0000;

constexpr control_t PASS         = 0;
constexpr control_t NOPASS       = (1UL << 8);
constexpr control_t DISCARD      = NOPASS;
constexpr control_t STORE        = NOPASS + (1UL << 9);
constexpr control_t REPLAY       = NOPASS + (1UL << 15);
constexpr control_t RETRIG       = (1UL << 16);
constexpr control_t PRNG         = (1UL << 17);

constexpr size_t POSITIONS = 8; // number of elements that can be stored in fast memory
constexpr size_t SHIFT_POSITION = 10;
constexpr control_t POSITIONS_MASK = (0b111UL << SHIFT_POSITION);
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

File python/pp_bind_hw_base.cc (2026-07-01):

// SPDX-License-Identifier: MIT
// Copyright (c) 2025 Rok Zitko

#include <cstdint>

#include <nanobind/stl/string.h>

#include "pp_bind.hh"

#include "fpga.hh"
#include "freq_meter.hh"
#include "pll_clk.hh"
#include "ppversion.hh"
#include "tidbit.hh"

using namespace nb::literals;

void bind_hw_base(nb::module_ &m) {
  nb::class_<loc>(m, "loc")
    .def(nb::init<std::uintptr_t>())
    .def("write", &loc::write, "val"_a, "offset"_a = uint32_t{0})
    .def("read", &loc::read, "offset"_a = uint32_t{0})
    .def("get_ptr", &loc::get_ptr);

  nb::class_<mm>(m, "mm")
    .def(nb::init<std::uintptr_t, std::uintptr_t>())
    .def("get_ptr", &mm::get_ptr,
         "ptr_base"_a = std::uintptr_t{0},
         "shift"_a = std::uintptr_t{0})
    .def("get_loc", &mm::get_loc,
         "ptr_base"_a = std::uintptr_t{0},
         "shift"_a = std::uintptr_t{0},
         nb::keep_alive<0, 1>());

  nb::class_<MGR>(m, "MGR")
    .def(nb::init<mm &, const Verbosity &>(),
         nb::keep_alive<1, 2>(),
         nb::keep_alive<1, 3>())
    .def("status", &MGR::status)
    .def("gpio_write", &MGR::gpio_write)
    .def("gpio_read", &MGR::gpio_read);

  nb::class_<hpsled>(m, "hpsled")
    .def(nb::init<mm &, std::uintptr_t>(),
         "dev"_a,
         "base"_a = std::uintptr_t(0xFF709000),
         nb::keep_alive<1, 2>())
    .def("on", &hpsled::on)
    .def("off", &hpsled::off);

  nb::class_<FPGA>(m, "FPGA")
    .def(nb::init<const Verbosity &, const int>(),
         "verbosity"_a,
         "expected_version"_a = version,
         nb::keep_alive<1, 2>())
    .def("check_version", &FPGA::check_version,
         "expected_version"_a = version,
         "verbose"_a = false)
    .def("status", &FPGA::status)
    .def("set_streamer_clk", &FPGA::set_streamer_clk)
    .def("streamer_done_config", &FPGA::streamer_done_config,
         "active_mask"_a,
         "armed_live_mask"_a)
    .def("streamer_active_mask", &FPGA::streamer_active_mask)
    .def("streamer_armed_live_mask", &FPGA::streamer_armed_live_mask)
    .def("output_enable", &FPGA::output_enable);

  nb::class_<freq_meter>(m, "freq_meter")
    .def("__init__", [](freq_meter *self,
                         const mm &dev,
                         const std::uintptr_t base,
                         const bool verbose) {
           new (self) freq_meter(dev, pp_bind_h2f_region(base), verbose);
         },
         "dev"_a,
         "base"_a,
         "verbose"_a = false,
         nb::keep_alive<1, 2>());

  nb::class_<pp_freq_meter>(m, "pp_freq_meter")
    .def(nb::init<InputParser &, FPGA &, const bool>(), nb::keep_alive<1, 3>())
    .def("report", &pp_freq_meter::report);

  nb::class_<sysid>(m, "sysid")
    .def(nb::init<mm &, const std::uintptr_t>(), nb::keep_alive<1, 2>())
    .def(nb::init<mm &, const std::uintptr_t, const uint32_t>(), nb::keep_alive<1, 2>())
    .def("get_id", &sysid::get_id);

  nb::class_<fifo>(m, "fifo")
    .def(nb::init<mm &, std::uintptr_t, std::uintptr_t>(), nb::keep_alive<1, 2>())
    .def("read", &fifo::read)
    .def("write", &fifo::write)
    .def("status", &fifo::status)
    .def("event", &fifo::event)
    .def("check", &fifo::check)
    .def("fill", &fifo::fill)
    .def("clear_fifo", &fifo::clear_fifo);

  nb::class_<pio>(m, "pio")
    .def(nb::init<mm &, std::uintptr_t>(), nb::keep_alive<1, 2>());

  nb::class_<pio_out, pio>(m, "pio_out")
    .def(nb::init<mm &, std::uintptr_t>(), nb::keep_alive<1, 2>())
    .def("write", &pio_out::write)
    .def("read", &pio_out::read);

  nb::class_<pio_in, pio>(m, "pio_in")
    .def(nb::init<mm &, std::uintptr_t>(), nb::keep_alive<1, 2>())
    .def("read", &pio_in::read)
    .def("mask", &pio_in::mask)
    .def("edgecapture", &pio_in::edgecapture)
    .def("edgecapture_clear", &pio_in::edgecapture_clear);

  nb::class_<pll>(m, "pll")
    .def(nb::init<mm &, std::uintptr_t>(), nb::keep_alive<1, 2>())
    .def("report", &pll::report)
    .def("set_N", &pll::set_N)
    .def("set_M", &pll::set_M)
    .def("set_C", &pll::set_C);

  nb::class_<pll_core_clk>(m, "pll_core_clk")
    .def(nb::init<mm &>(), nb::keep_alive<1, 2>())
    .def("set_core_clk", &pll_core_clk::set_core_clk,
         "opts"_a,
         "verbosity"_a);

  nb::class_<pll_int_clk>(m, "pll_int_clk")
    .def(nb::init<mm &>(), nb::keep_alive<1, 2>())
    .def("set_int_clk", &pll_int_clk::set_int_clk,
         "opts"_a,
         "verbosity"_a);
}

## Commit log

2025-11-29 Initial public version
    [LEDs.kicad_sch, aux.kicad_sch, ext_clk.kicad_sch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]
2025-12-18 Bill of materials
    [shield.csv, shield.xlsx]
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2025-12-25 add test16 for periodic toggling on all output pins with period that increases in proportion to pin index; useful for testing output correctness on all pins
2025-12-25 Testing the I2C interface
2026-01-18 Scripts for reading on-board temperature sensor and setting the on-board DAC
2026-01-27 clip, reject settings for filtering input to PID
2026-01-28 deadband and leaky integration in PID
2026-01-29 averaging of error signal for PID control in GPSDO
2026-02-14 add low jitter PLL settings
2026-02-22 delay calls using thread,chronos
2026-02-25 switchable clock source using cleaning PLL for the externally supplied reference clock
2026-03-06 report on on-board xtal clock
2026-03-18 repeated emission of the same sequence through DMA + tests
2026-03-27 docs: expand clocking and timing reference
    Document the current clock tree, clock switching, software PLL control, and SDC timing model in more detail.
    Also align the shorter overview and test notes with the fuller clock-domain reference.
2026-03-28 tool for generating the SPI sequence for setting the output voltage on PMMODDA3 16-bit DAC module
2026-03-28 Switch to standalone asio
2026-03-28 c++: separate FPGA startup policy from board access
    Move process and board startup policy into a small bootstrap layer and keep FPGA focused on MMIO and low-level board access.
    Update pptool and ppscpi to use the shared startup path without changing their overall runtime behavior.
2026-04-01 rename a constant due to possible conflict; add missing header
    [config.h]
2026-04-01 extend sequence stream parser stage 1
2026-04-01 extend sequence stream parser stage 2
2026-04-01 extend sequence stream parser stage 3
2026-04-01 extend sequence stream parser stage 4
2026-04-01 split SPI helpers into dedicated headers
2026-04-01 add PMOD DA3 SPI sweep pptest
2026-04-01 add DMA PMOD DA3 sine test
2026-04-01 tighten documentation consistency
2026-04-01 document startup and trigger control flow
2026-04-01 refine PP_PMOD connector documentation
2026-04-02 add bash completion for board tools
2026-04-02 stage bash completion in copy flows
2026-04-03 tighten service and testing docs
2026-04-06 I2C OLED display test
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2026-04-11 stabilize ppwebgui single-stream control and reset flow
    Reshape the web UI around a single active streamer, add trigger/reset reporting, and keep browser-managed state coherent across hardware actions. Route manual output override through the combiner so the deployed hardware avoids the crashing streamer override register path.
2026-04-11 make ppwebgui stream final qout deterministic
    Reuse the tracked idle raw qout as the browser stream final value so web-triggered runs stop ending in a random state. Keep the snapshot-backed status and reset flow aligned with that deterministic final output.
2026-04-11 give ppwebgui a fresh reset before each stream
    Run the existing bring-up path before browser-triggered streaming so each launch starts from a clean hardware state. Keep the deterministic final qout behavior aligned with the manual reset flow.
2026-04-12 extract ppwebgui hardware controller into service module
    Move WebGuiController and its hardware-facing helpers out of ppwebgui.cc so the GUI and HTTP layer stop sharing a translation unit with the fragile hardware-control path. Keep the public behavior unchanged while establishing a clear service boundary for later tightening.
2026-04-12 document anchored hardware lifetime rules
    Record the ppwebgui ownership rule in code comments, maintainer docs, and workspace guidance so future refactors keep the hardware controller anchored in one instance. Make the controller explicitly non-copyable and non-movable so accidental lifetime changes fail at compile time instead of on the board.
2026-04-12 split ppwebgui runtime config from input parsing
    Resolve ppwebgui startup and policy settings into a pure WebGuiRuntimeConfig in main, then pass that config into the anchored controller instead of storing the raw InputParser. Keep the hardware-owning controller instance fixed in place while reducing parser coupling inside the service and reset paths.
2026-04-12 rename ppwebgui entry point and document module map
    Rename the remaining ppwebgui main translation unit to ppwebgui_main.cc and document the current module layout in the C++ README. This keeps the layered structure explicit without changing the anchor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
2026-04-12 extract ppwebgui server lifecycle
    Move httplib server creation, route/asset wiring, and bind/listen control into a dedicated server module while keeping the hardware controller anchored in the app layer. This narrows the app runner t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
2026-04-12 tighten ppwebgui frontend header boundaries
    Reduce include coupling across the non-hardware ppwebgui layers by forward-declaring the shared frontend value types and passing them by const reference. Keep the runtime behavior and anchored hardware-controller lifetime unchanged while making the GUI-side interfaces lighter and more explicit.
2026-04-12 document final ppwebgui architecture split
    Update the maintainer docs to reflect the completed ppwebgui layering, control flow, and pure-value boundaries between the app, server, HTTP, and hardware-owning service layers. Record the anchored WebGuiController ownership rule alongside the final module map so future changes can extend the system without reintroducing the earlier lifetime bugs.
2026-04-12 document editable trigger settings in ppwebgui
    Update the ppwebgui docs to describe the new trigger editing flow, the semantic trigger modes exposed in the browser, and the POST /api/trigger endpoint. Clarify that AUX trigger fields remain visibl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
2026-04-13 track ppwebgui clock state and measurements
    Add tracked clock settings and measured clock snapshots to ppwebgui status so runtime clock changes can later persist across reset and stream operations. Initialize that state from startup config, reapply the tracked clock settings during reset, and store measured ext/int/streamer/core frequencies in the controller snapshot.
2026-04-13 refine ppwebgui clocking controls and docs
    Switch the browser clock profile inputs to preset PLL pull-down menus with 100M as the initial default while still surfacing nonstandard tracked profiles honestly. Update the ppwebgui and clock-domai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
2026-04-13 harden ppscpi session handling and shutdown semantics
    Contain SCPI handler exceptions inside the generic session layer so malformed or failing commands stop affecting only the current request instead of tearing down the whole server. Add explicit DISCONNECT and TERMINATE semantics so clients can close one session cleanly or shut down the whole ppscpi process intentionally.
2026-04-17 add AD9833 SPI payload target
    Split the standalone SPI payload generator around a shared 32-bit encoder so the new 5 MHz AD9833 sequence can drive qout[16..19] without breaking the existing PMODDA3 binary.
2026-04-17 refactor AD9833 payload generator
    Wrap the AD9833 register model in a compact helper so the 5 MHz example can express control and register words by datasheet meaning while preserving the exact emitted SPI sequence.
2026-04-17 add AD9833 amplifier payload target
    Add an MCP41010 helper and a third spi_payload binary so the DollaTek module can be programmed for the same 5 MHz AD9833 setup plus the board's approximate 5x amplified-output stage from one generate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
2026-04-17 flatten element storage
    Store raw control/count/value fields inside el instead of shared wrapper objects while preserving the existing constructor surface and semantic behavior covered by the unit tests.
2026-04-17 share element control decoding
    Centralize raw control-word and trigger-field decoding in el so binary reconstruction and text serialization reuse the same helper logic, with regression tests covering the shared decoders.
2026-04-17 move element reconstruction into el
    Keep raw triplet decoding in the element type itself so binary readers reuse the same reconstruction rules and tests cover the shared path directly.
2026-04-17 add immutable element transforms
    Replace the last setter choreography with immutable el helpers, derive element kind from control, and centralize regular token parsing so sequence reconstruction and text conversion share the same rules.
2026-04-17 deduplicate element mode semantics
    Unify regular mode metadata, wrapper behavior, and storage helpers so element reconstruction, token handling, and Value operations share the same implementation without changing the on-wire formats.
2026-04-17 move text element formatting into el
    Let elements render their own text-sequence records so the sequence writer becomes a thin stream loop and the record formatting rules live alongside the element semantics they encode.
2026-04-20 align Python element bindings
    Update the Python bindings, tests, and docs to the flattened el API, add the missing retrig/prng surface, and make the board-side test fixture tolerate frequency-meter layouts that do not expose the expected channel count.
2026-04-20 refresh element API docs
    Document the flattened el model and preferred immutable helper style in the maintainer-oriented READMEs so contributors do not follow the older raw-constructor and setter-heavy patterns.
2026-04-20 tighten include hygiene
    Add missing direct includes and drop clearly unused ones in the audited project-owned C++ sources so core headers, tools, and bindings rely less on transitive includes.
2026-04-20 split Python bindings across translation units
    [pp_bind_hw_base.cc]
2026-04-21 harden transport stall timeouts
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2026-04-21 expand board smoke failure coverage
2026-04-22 polish docs landing and dev workflow
    Turn the docs front door into a hardware-first guide, upgrade the weakest command pages, add a unified host-side dev-check target, and align CI and testing docs around dev-check, board-smoke, and run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
2026-04-22 add missing header file for on-board builds
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2026-06-05 fix servo PWM duty units
2026-06-06 fix ppfreq sample count
2026-06-07 refresh python bindings for fpga api
    [pp_bind_hw_base.cc]
2026-06-07 fix ppfg servo option docs
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2026-06-27 Tighten streamer FIFO handling and tests
2026-06-28 Fix finite DMA sine playback
2026-06-28 Fix finite DMA loop playback
2026-06-29 Fix Python binding API issues
    [pp_bind_hw_base.cc]
2026-06-29 Fix mounted image copy safety
2026-06-29 Fix I2C validation and clock readback
2026-07-01 Fix SPI count merge overflow
2026-07-01 Tighten SCPI and timestamp tests
2026-07-01 Warn on external socket binds
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2026-07-03 Avoid InputParser access from worker threads
2026-07-03 Fix trigger reset stage preservation
